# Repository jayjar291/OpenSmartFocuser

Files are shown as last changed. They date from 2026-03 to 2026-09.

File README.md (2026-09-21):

# OpenSmartFocuser

OpenSmartFocuser is an open-source telescope focuser project with:
- ESP32-S3 firmware (display/menu, motor control, serial command handling)
- an INDI driver scaffold for host-side integration
- hardware design files for PCB and related fabrication assets

## Build Targets

- `firmware/` contains the PlatformIO project for the device firmware.
- `drivers/indi/` contains the CMake-based INDI focuser driver.

## Folder Structure

```text
OpenSmartFocuser/
├── .github/
│   ├── ISSUE_TEMPLATE/        # GitHub issue templates
│   └── workflows/             # CI workflows (firmware and INDI driver builds)
├── docs/                      # Project documentation and operating notes
├── drivers/
│   └── indi/                  # INDI driver scaffold and CMake config
├── firmware/
│   ├── include/               # Firmware headers/config
│   ├── src/                   # Firmware source code
│   ├── platformio.ini         # PlatformIO project config
│   └── backup/                # Local backup files
└── hardware/
    ├── README.md              # Hardware folder overview
    ├── cad/                   # Mechanical CAD-related files
    │   └── README.md          # CAD file overview
    └── pcb/                   # KiCad project and fabrication outputs
        ├── README.md          # PCB project overview
        └── fabrication/       # Fabrication export guidance and outputs
```

## Continuous Integration

- `firmware-build.yml` builds the firmware project on Ubuntu with PlatformIO.
- `indi-driver-build.yml` configures and builds the INDI driver on Ubuntu with system INDI, Nova, GSL, and ZLIB development packages.

## Local Builds

Firmware:

```bash
cd firmware
pio run
```

INDI driver:

```bash
cd drivers/indi
cmake -S . -B build
cmake --build build --parallel
sudo cmake --install build
sudo udevadm control --reload-rules
sudo udevadm trigger
```

The INDI driver build expects CMake, a C++ compiler, and the development packages for INDI, Nova, GSL, and ZLIB.
The install step also deploys a udev rule that creates the stable serial symlink `/dev/OSF` for OpenSmartFocuser devices (USB VID:PID `1209:F0C1`).

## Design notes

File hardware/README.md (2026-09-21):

# Hardware

This folder contains the mechanical and electronic source files for the OpenSmartFocuser build.

## Folder Structure

```text
hardware/
├── cad/  # Mechanical CAD models and related design artifacts
└── pcb/  # KiCad project files and fabrication outputs
```
├── cad/   # Mechanical CAD models, drawings, and exports
└── pcb/   # KiCad PCB source files and fabrication assets
```

## What Belongs Here

- Mechanical source files used to model the focuser assembly.
- PCB design files used to route, review, and manufacture the controller board.
- Exported files that are still part of the design source, such as STEP, DXF, and fabrication references.

## Related Files

- See [CAD files](cad/README.md) for the mechanical design folder.
- See [PCB files](pcb/README.md) for the KiCad project and fabrication workflow.

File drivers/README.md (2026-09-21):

# Drivers

Host-side driver integrations for OpenSmartFocuser.

## Folder Structure

```text
drivers/
└── indi/  # INDI focuser driver source, build files, and XML metadata
```

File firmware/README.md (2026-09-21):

# Firmware

ESP32-S3 firmware for OpenSmartFocuser, including motor control, menu/display UX, and serial command handling.

## Folder Structure

```text
firmware/
├── include/        # Firmware headers and configuration values
├── src/            # Firmware implementation files
├── platformio.ini  # PlatformIO build configuration
└── backup/         # Local backup snapshots (not part of firmware runtime)
```

## Build

```bash
cd firmware
pio run
```

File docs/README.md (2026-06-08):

# Documentation

This folder contains the operating notes for the firmware, menu system, serial protocol, and hardware configuration.

## What the Focuser Can Do

- Move the focuser to an absolute step position.
- Move the focuser relative to the current position.
- Home the focuser and report position, speed, limits, and movement state.
- Store, recall, edit, and remove presets.
- Control optional add-ons such as a shutter servo and flat panel.
- Run the on-device menu for local operation and settings changes.

## Menu Navigation

The on-device menu is driven by the physical buttons defined in the board pin configuration.

- `UP` moves through menu items or increases a setting.
- `DOWN` moves through menu items or decreases a setting.
- `SELECT` opens the highlighted item, confirms a setting, or starts the selected action.
- `ENDSTOP` is used by the firmware as a hardware input for homing and safety logic, not as a normal menu button.
- `BOOT` is the ESP32 bootloader pin and is used for flashing or recovery.

The main menu currently exposes presets, device information, homing, settings, motor enable/disable, and optional add-on controls when those features are compiled in.

## Serial Protocol

Serial commands must be framed as `:TOKENpayload#`.

The protocol is intended for host software, automation, and debugging. Use the commands below when you need to query state, control motion, manage presets, or integrate with external software.

### Status and Query Commands

- `:PP#` heartbeat. Use this to confirm the device is alive and the serial link is working.
- `:GP#` get the current focuser position in steps. Use this before or after movement when syncing state with host software.
- `:GM#` get the current movement state. Use this to check whether the focuser is idle, moving, homing, or in error.
- `:GS#` get the current speed preset. Use this when a client needs to mirror the active speed setting.
- `:GL#` get the configured software limits. Use this before issuing travel commands if your client needs to enforce range checks.
- `:CI#` get the configured motor current in milliamps. Use this for diagnostics or driver verification.
- `:CU#` get the configured microstep setting. Use this for diagnostics or startup validation.
- `:VF#` get firmware version. This command is listed in the protocol index but is currently a placeholder in the firmware.

### Movement Commands

- `:MA<steps>#` move to an absolute position. Use this for direct positioning when the target step count is already known.
- `:MR<steps>#` move relative to the current position. Use this for jog-style movement or small corrections.
- `:MH#` halt motion immediately. Use this as the emergency stop command.
- `:MS<0-4>#` set the movement speed preset. Use this when you need to switch between the configured speed profiles.
- `:SP<steps>#` override the current position. Use this only when you need to re-synchronize the software position after maintenance or a manual mechanical reset.

### Homing and System Commands

- `:HM#` start homing. Use this to find the reference position after power-up or when you need to re-establish the travel origin.
- `:TM#` toggle the motor enable state. Use this for quick local control when the current state is unknown.
- `:DM#` disable the motor. Use this when you want to cut motor drive without changing the rest of the device state.
- `:EM#` enable the motor. Use this before moving if the motor has been disabled.
- `:RB#` reboot the system. Use this only when the device is idle or when you intentionally need a restart.

### Preset Commands

- `:PL#` list stored presets. Use this to populate a preset browser in host software.
- `:PR<presetId>#` get a preset by ID. Use this when you need the name and step value for one stored preset.
- `:PA<steps>,<name>#` add a new preset. Use this when saving the current position as a named target.
- `:PS<presetId>,<steps>,<name>#` update an existing preset. Use this when renaming or retargeting a stored preset.
- `:PG<presetId>#` go to a preset by ID. Use this for one-touch recall from the stored list.
- `:PC<presetId>#` delete a preset by ID. Use this when removing outdated entries.

### Star Map Target Commands

- `:TI#` get the current DSO target.
- `:TG<RA>,<DEC>,<name>#` set the DSO target.
- `:TC#` clear the DSO target.

These commands are currently placeholders in the firmware and return a temporary response. Do not depend on them for production automation yet.

### Optional Add-on Commands

- `:AQ#` query installed add-ons. Use this to detect whether the shutter or flat panel is present.
- `:FP<brightness>#` set flat panel brightness from 0 to 255. Use this only when the flat panel add-on is installed.
- `:SV<position>#` set the shutter position. Use this only when the shutter add-on is installed.

## Optional Add-ons

The firmware can expose two optional accessories.

- Shutter servo: controlled by `PIN_SHUTTER_SERVO` and exposed through the shutter menu and `:SV` command.
- Flat panel: controlled by `PIN_FLAT_FRAME_PANEL` and exposed through the menu and `:FP` command.

If an add-on is not compiled into the current build, the related menu items and commands should not be relied on.

## Current Pin Definitions

These pins come from [firmware/include/board_config/esp32_s3_devkitc1_pins.h](../firmware/include/board_config/esp32_s3_devkitc1_pins.h).

| Function | Pin | Notes |
| --- | ---: | --- |
| `PIN_TMC_STEP` | 4 | Step output for the TMC2209 driver |
| `PIN_TMC_DIR` | 5 | Direction output for the TMC2209 driver |
| `PIN_TMC_ENABLE` | 6 | Enable output for the TMC2209 driver |
| `PIN_TMC_UART_TX` | 15 | UART TX for driver configuration |
| `PIN_TMC_UART_RX` | 16 | UART RX for driver configuration |
| `PIN_LCD_SCK` | 12 | ST7789 SPI clock |
| `PIN_LCD_MOSI` | 11 | ST7789 SPI data out |
| `PIN_LCD_MISO` | -1 | Not used |
| `PIN_LCD_CS` | 10 | ST7789 chip select |
| `PIN_LCD_DC` | 9 | ST7789 data/command |
| `PIN_LCD_RST` | 8 | ST7789 reset |
| `PIN_LCD_BL` | 17 | Backlight control |
| `PIN_LED` | 48 | On-board/status LED |
| `PIN_BUTTON_UP` | 35 | Menu up input |
| `PIN_BUTTON_DOWN` | 37 | Menu down input |
| `PIN_BUTTON_SELECT` | 36 | Menu select input |
| `PIN_BUTTON_ENDSTOP` | 38 | Endstop/safety input |
| `PIN_BUTTON_BOOT` | 0 | Bootloader input |
| `PIN_SHUTTER_SERVO` | 18 | Optional shutter add-on |
| `PIN_FLAT_FRAME_PANEL` | 13 | Optional flat panel add-on |

## Notes

- The menu and serial protocol should stay aligned with the current firmware behavior.
- If you change the board or add-ons, update the pin definition file first and then refresh this document.
- If a serial command is added or removed, update the command list here at the same time.

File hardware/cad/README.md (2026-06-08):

# CAD

This folder stores the mechanical design files for the OpenSmartFocuser assembly.

## Folder Structure

```text
cad/
├── 3mf/   # Printable model exports
├── step/  # Assembly and fit-check models
└── pcb mount.dxf  # 2D reference drawing for the PCB mount
```

## File Types

- `3mf/` contains printable parts for enclosure and accessory checks.
- `step/` contains solid models for CAD import, fit checks, and assembly review.
- `pcb mount.dxf` is the 2D drawing used for mount or cut reference work.

## Use Case

Use this folder when you need to:

- review the physical assembly before printing or machining.
- verify clearances between the drawtube, housing, and mounted electronics.
- export or update models for enclosure and mechanical integration.

When mechanical dimensions change, update the source CAD files first and then regenerate the derived exports.

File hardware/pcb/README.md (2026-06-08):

# PCB

This folder contains the KiCad project and related fabrication assets for the OpenSmartFocuser controller board.

## Folder Structure

```text
pcb/
├── OpenSmartFocuser/  # KiCad project source files
├── fabrication/       # Fabrication export guidance and output files
```

## Contents

- `OpenSmartFocuser/` contains the schematic, board layout, symbols, footprints, and project metadata.
- `fabrication/` is reserved for Gerber, drill, BOM, and pick-and-place outputs.

## Use Case

Use this folder when you need to:

- edit the schematic or PCB layout in KiCad.
- review net names, footprints, and placement.
- generate manufacturer-ready fabrication files.

Keep fabrication exports separate from the source project so the design files remain easy to review and version.

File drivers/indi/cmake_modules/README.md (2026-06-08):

This folder is intentionally scaffolded for INDI CMake modules.

Copy the following files from the upstream libindi repository when you are ready to build:
- CMakeCommon.cmake
- FindINDI.cmake
- FindNova.cmake
- UnityBuild.cmake

Source:
https://github.com/indilib/indi/tree/master/cmake_modules

The GitHub Actions INDI driver workflow fetches these files automatically during CI builds.

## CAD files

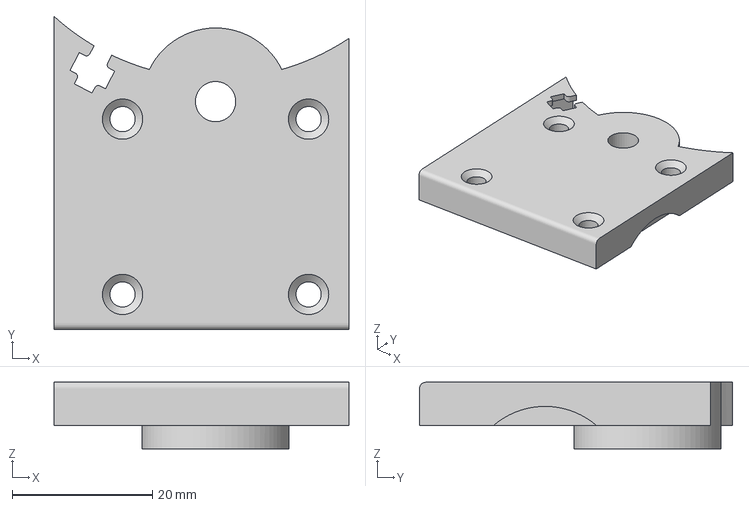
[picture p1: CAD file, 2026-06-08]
hardware/cad/3mf/Cap.3mf
42.0 x 44.6 x 9.50 mm

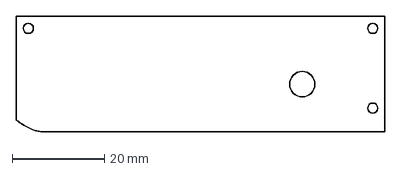
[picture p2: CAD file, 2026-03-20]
hardware/cad/pcb mount.dxf
80.0 x 25.0 mm

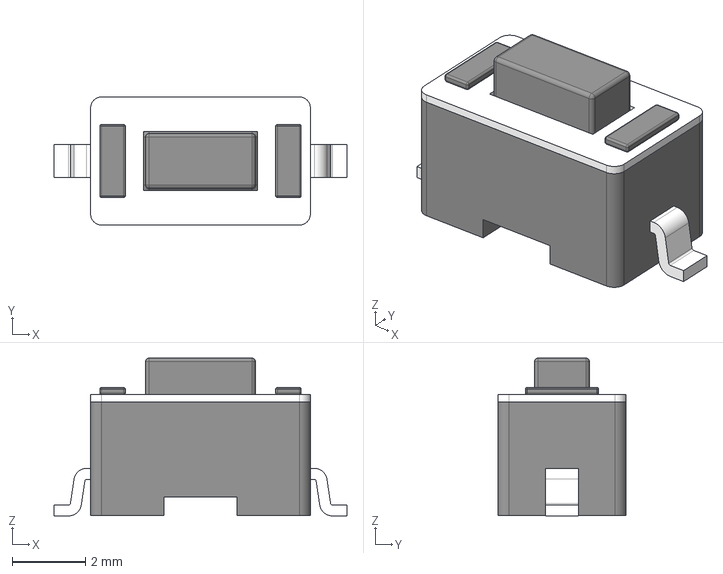
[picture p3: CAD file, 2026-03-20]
hardware/pcb/OpenSmartFocuser/EASYEDA_MODELS/SW-SMD_L6.0-W3.5-LS8.0-1.step
8.00 x 3.50 x 4.31 mm

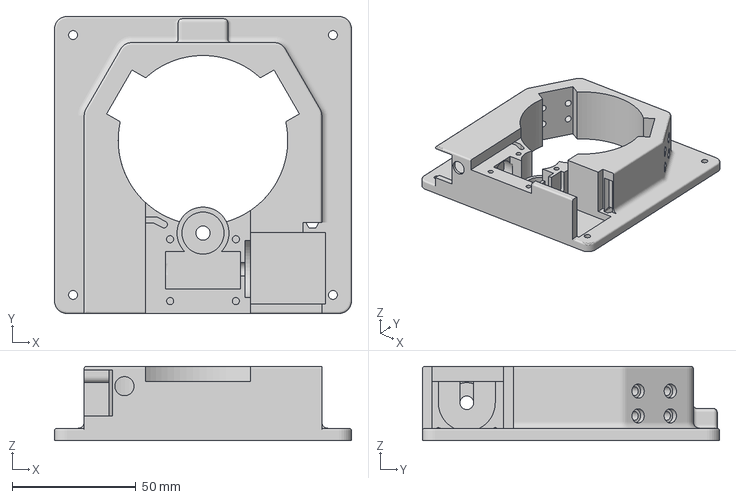
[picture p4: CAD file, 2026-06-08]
hardware/cad/3mf/Housing.3mf
120.0 x 120.0 x 30.0 mm

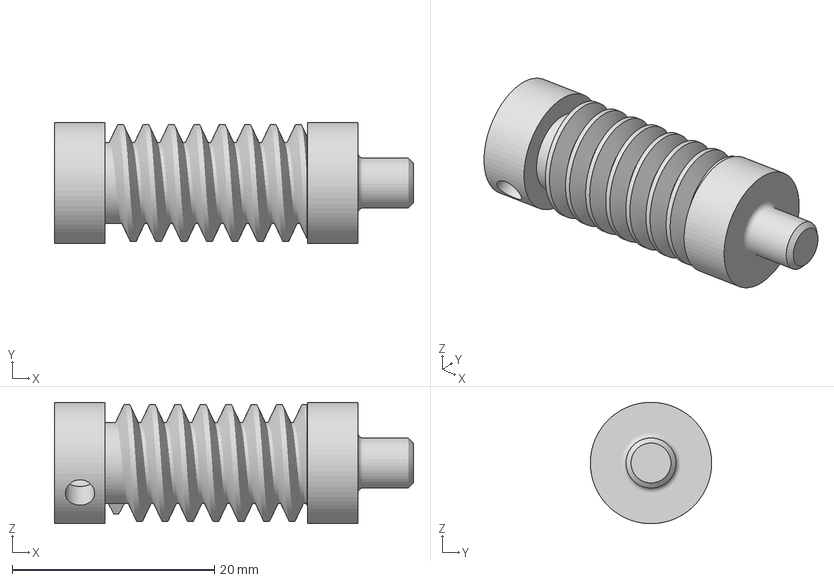
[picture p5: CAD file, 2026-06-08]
hardware/cad/3mf/Input.3mf
35.5 x 12.0 x 12.0 mm

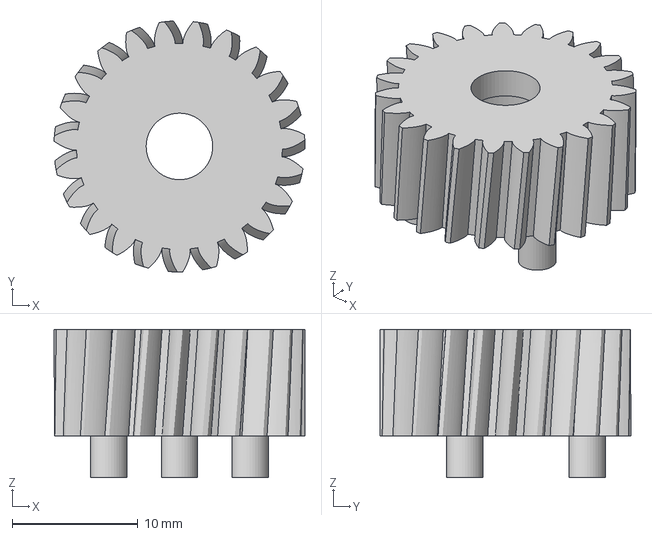
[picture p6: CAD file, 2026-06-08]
hardware/cad/3mf/Output.3mf
20.0 x 20.0 x 11.8 mm

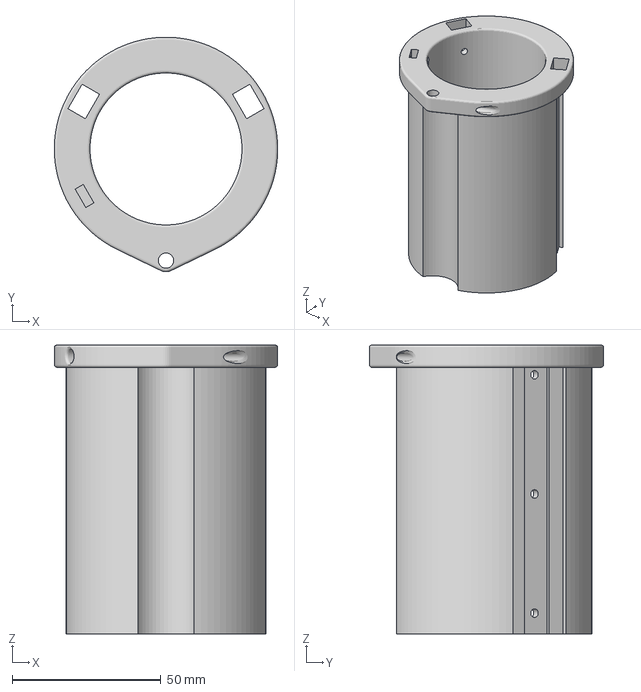
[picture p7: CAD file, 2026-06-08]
hardware/cad/3mf/Drawtube.3mf
75.0 x 78.7 x 97.0 mm

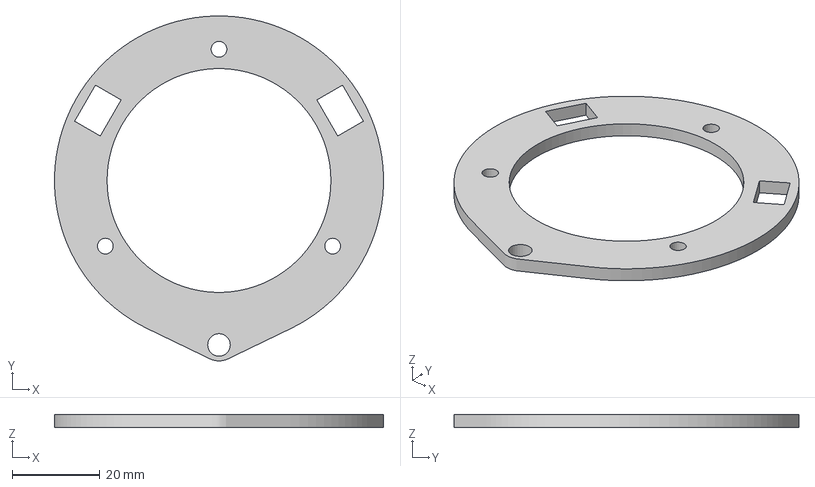
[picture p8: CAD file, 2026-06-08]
hardware/cad/3mf/End Cap.3mf
75.0 x 78.6 x 3.00 mm

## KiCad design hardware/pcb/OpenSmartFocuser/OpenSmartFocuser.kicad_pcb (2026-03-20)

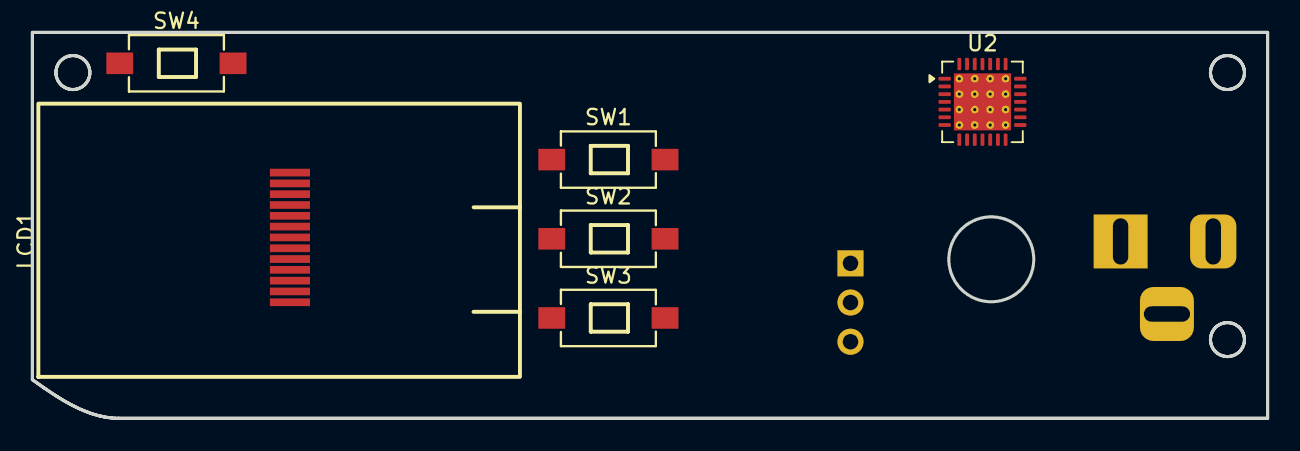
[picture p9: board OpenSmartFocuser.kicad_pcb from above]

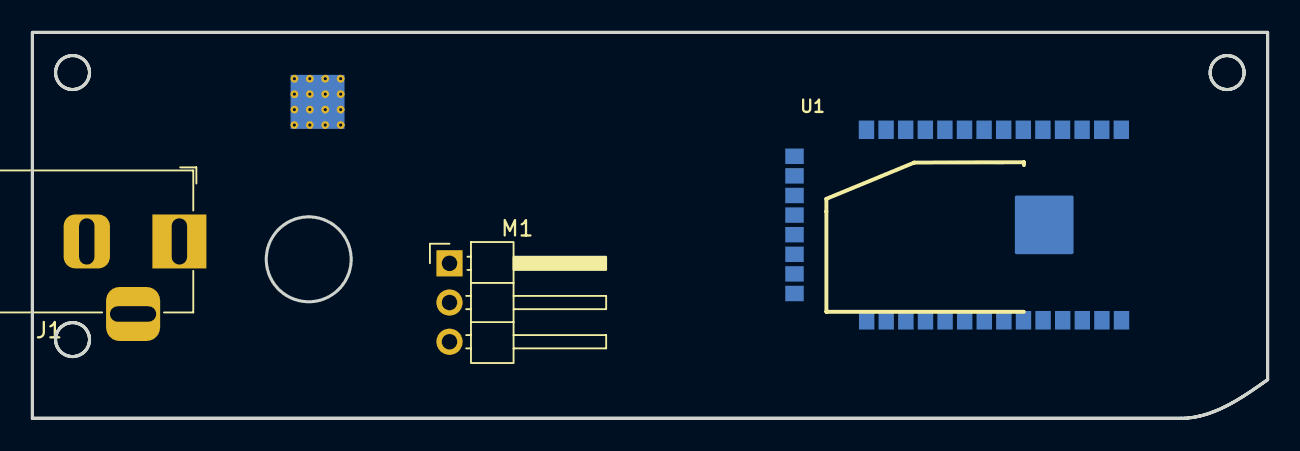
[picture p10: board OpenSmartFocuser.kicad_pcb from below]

Board: 2 copper layers, 80.0 x 25.0 mm, 9 parts (3 on the bottom side), 2 nets, no tracks yet.

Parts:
J1: Barrel_Jack_Switch; BarrelJack_Horizontal
LCD1: LCD-SMD_1.14IPS-LCD
M1: Motor_Servo; PinHeader_1x03_P2.54mm_Horizontal
SW1, SW2, SW3, SW4: SW-SMD_L6.0-W3.5-LS8.0-1
U1: NanoS3
U2: TMC2209-LA; VQFN-28-1EP_5x5mm_P0.5mm_EP3.7x3.7mm_ThermalVias

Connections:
unnamed: U2.3 (GND), U2.18 (GND), U2.29 (GND)
unnamed: U2.22 (VS), U2.28 (VS)

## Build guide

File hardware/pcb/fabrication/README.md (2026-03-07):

# Fabrication Outputs

Place Gerber files, BOM, and pick-and-place exports here after generating from KiCad.

## Files Expected
- `gerbers/` — Gerber + drill files (ZIP for fab upload)
- `BOM.csv` — Bill of Materials
- `positions.csv` — Pick and place / CPL file

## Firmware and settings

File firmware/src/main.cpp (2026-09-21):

#include <Arduino.h>
#include <FastAccelStepper.h>
#include <TMCStepper.h>
#include <freertos/FreeRTOS.h>
#include <freertos/task.h>
#if CONFIG_TINYUSB_ENABLED
#include <USB.h>
#endif
#include "addons.h"
#include "config.h"
#include "debug_serial.h"
#include "menu.h"
#include "movement.h"
#include "serial_command_handler.h"
#include "preset.h"

/*
 * Hardware interface constants for TMC2209 UART control.
 */
static constexpr float TMC_R_SENSE = 0.11f;
static constexpr uint8_t TMC_STEPPER_UART_INDEX = 1;
// globlal variables for idle star map center coordinates
float idleMapCenterRaDeg = IDLE_STAR_MAP_CENTER_RA_DEG;
float idleMapCenterDecDeg = IDLE_STAR_MAP_CENTER_DEC_DEG;

/*
 * Global hardware driver instances used during initialization and runtime.
 */
HardwareSerial tmcSerial(TMC_STEPPER_UART_INDEX);
FastAccelStepperEngine stepperEngine;
FastAccelStepper* focuserStepper = nullptr;
TMC2209Stepper focuserDriver(&tmcSerial, TMC_R_SENSE, TMC_DRIVER_ADDRESS);

/*
 * Global motor enable state controlled from the main menu.
 */
bool motorEnabled = false;

static TaskHandle_t motorTaskHandle = nullptr;

#if CONFIG_TINYUSB_ENABLED
namespace {

struct UsbDescriptorConfigurator {
  UsbDescriptorConfigurator() {
    USB.VID(0x1209);
    USB.PID(0xF0C1);
    USB.manufacturerName("JayTek");
    USB.productName("OpenSmartFocuser");
  }
};

UsbDescriptorConfigurator gUsbDescriptorConfigurator;

}  // namespace
#endif

static void motorTask(void* /*param*/) {
  static constexpr uint32_t kHealthCheckIntervalMs = 250;
  uint32_t lastHealthCheckMs = 0;

  for (;;) {
    Movement::processEndstopEvent();
    Movement::updateSoftEndstops();
    Movement::updateHoming();
    Movement::updatePositionPersistence();
    Movement::updateMotorIdleTimeout();
    
    const uint32_t now = millis();
    if (now - lastHealthCheckMs >= kHealthCheckIntervalMs) {
      Movement::healthCheck();
      lastHealthCheckMs = now;
    }
    
    vTaskDelay(pdMS_TO_TICKS(1));
  }
}

/*
 * One-time startup sequence for serial logging, UI initialization,
 * and TMC driver bring-up.
 */
void setup() {
#if CONFIG_TINYUSB_ENABLED && !ARDUINO_USB_CDC_ON_BOOT
  // Initialize TinyUSB descriptors before CDC starts so host sees custom IDs/names.
  USB.VID(0x1209);
  USB.PID(0xF0C1);
  USB.manufacturerName("JayTek");
  USB.productName("OpenSmartFocuser");
  USB.begin();
#endif

  Serial.begin(115200);
  delay(100);

#if CONFIG_TINYUSB_ENABLED
  const uint32_t serialWaitStartMs = millis();
  while (!Serial && (millis() - serialWaitStartMs) < 2000) {
    delay(10);
  }
#endif

  SerialCommandHandler::begin(Serial);

  DebugSerial::printFramed("Setup: begin");
  DebugSerial::printFramedValue("Free heap at startup (bytes) ", ESP.getFreeHeap(), " ");
  
  initMenu();

  ledcSetup(7, 5000, 8); // Set up PWM on channel 7 with 5 kHz frequency and 8-bit resolution for LCD backlight control
  ledcAttachPin(PIN_LCD_BL, 7); // Attach the LCD backlight pin to PWM channel 7
  
  DebugSerial::printFramed("Setup: initialize addons");
  DebugSerial::printFramedValue("Free heap (bytes) ", ESP.getFreeHeap(), " ");
  if (Addons::isEnabled()) {
    Addons::initializeAddons();
  }

  DebugSerial::printFramed("Setup: initializeDriver");
  Movement::initializeDriver();
  DebugSerial::printFramedValue("Free heap (bytes) ", ESP.getFreeHeap(), " ");
  
  DebugSerial::printFramed("Setup: preset begin");
  preset::begin();
  DebugSerial::printFramedValue("Free heap (bytes) ", ESP.getFreeHeap(), " ");

  // Core 0 handles motor/homing/endstop tasks. loop() remains on Core 1 for UI/menu.
  DebugSerial::printFramed("Setup: create motor task");

  BaseType_t taskCreated = xTaskCreatePinnedToCore(
    motorTask,
    "motorTask",
    4096,
    nullptr,
    2,
    &motorTaskHandle,
    0);
    if (taskCreated != pdPASS) {
      DebugSerial::printFramed("Failed to start motor task on Core 0");
      return;
    }
  DebugSerial::printFramedValue("Free heap (bytes) ", ESP.getFreeHeap(), " ");



  DebugSerial::printFramed("Setup: done");
}

/*
 * Main runtime loop: services menu input/rendering and applies
 * current brightness setting to the display backlight PWM pin.
 */
void loop() {
  menu.loop();
  SerialCommandHandler::poll();
  Movement::setSpeedSetting(getFocusSpeedSetting());
  //analogWrite(PIN_LCD_BL, getBrightnessSetting() * 255 / 100);
  ledcWrite(7, getBrightnessSetting() * 255 / 100); // Apply brightness setting to LCD backlight PWM channel
  Addons::detachServos(); // Detach servos if they have been idle for a while to reduce power consumption and prevent jitter
}

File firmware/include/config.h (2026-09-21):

#pragma once

//#include "board_config/esp32_s3_devkitc1_pins.h"
#include "board_config/esp32_s3_mainboard_OSF.h"

/*
 * TFT_eSPI is configured through a custom setup header passed in build flags.
 */
#define TFT_ESPI_SETUP_HEADER "TFT_eSPI_Setup.h"

/*
 * Generic motion and UART timing configuration for the focuser driver stack.
 * System now runs in full-step mode (1 microstep) for all operations.
 */
#define TMC_UART_BAUDRATE 115200
#define TMC_DRIVER_ADDRESS 0b00
#define TMC_MAX_SPEED 30000
#define TMC_MAX_ACCELERATION 50000
// Speed settings for different focus jog modes and preset saving.
#define FINE_FOCUS_SPEED_STEPS_PER_SEC 3000
#define SLOW_FOCUS_SPEED_STEPS_PER_SEC 6000
#define MEDIUM_FOCUS_SPEED_STEPS_PER_SEC 9000
#define FAST_FOCUS_SPEED_STEPS_PER_SEC 12000
#define MAX_FOCUS_SPEED_STEPS_PER_SEC 15000
#define HOMING_SPEED_STEPS_PER_SEC 20000

/*
 * Enables framed debug text output on Serial as !{message}*.
 * Protocol responses remain unchanged.
 */
#define SERIAL_DEBUG_ENABLED true

/*
 * TMC2209 electrical and mode settings used during driver initialization.
 */
#define TMC_RMS_CURRENT 650
#define MOTOR_IDLE_TIMEOUT_MS 30000
#define TMC_MICROSTEPS 16
#define TMC_SPREAD_CYCLE true

/*
 * Focuser travel calibration.
 * Measured: 184000 full steps (HOMING_MICROSTEPS=1) = 4.74 mm.
 * FOCUSER_STEPS_PER_MM is in runtime step units (full-step mode).
 */
#define FOCUSER_STEPS_PER_MM 38819

/*
 * Software travel limits (enforced in normal operating mode).
 */
#define FOCUSER_SOFT_MIN_MM    0
#define FOCUSER_SOFT_MAX_MM    55
#define FOCUSER_SOFT_MIN_STEPS 0
#define FOCUSER_SOFT_MAX_STEPS (FOCUSER_SOFT_MAX_MM * FOCUSER_STEPS_PER_MM)
#define FOCUSER_HOMING_RETURN_MM 1

/*
 * User-facing device defaults used by the menu/UI layer.
 */
#define DEFAULT_BRIGHTNESS 75

/*
 * Enables PSRAM initialization during startup when hardware supports it.
 * Set to true to attempt PSRAM init, false to skip.
 */
#define ENABLE_PSRAM true

/*
 * Hard-coded preset names exposed in the menu when adding a new preset.
 * Keep this list at or below preset::kMaxPresets entries.
 */
#define PRESET_NAME_OPTIONS { \
	"Fine Focus",              \
	"Clear",              \
	"Dark",              \
	"Red",              \
	"Green",              \
	"Blue",              \
	"Luminance",              \
	"Ha",              \
	"O-III",              \
	"S-II",             \
	"UV",             \
	"IR"              \
}

/*
 * Idle star-map center (J2000-like sky coordinates, degrees).
 * Right ascension wraps 0..360; declination is clamped to -90..90.
 */
#define IDLE_STAR_MAP_CENTER_RA_DEG 90.0f
#define IDLE_STAR_MAP_CENTER_DEC_DEG 20.0f

/*
 * Select which star catalog is compiled into the idle sky map.
 * Options in this repo: "stars.h", "stars_large.h", "stars_6.5.h"
 */
#define IDLE_STAR_CATALOG_HEADER "stars_6.5.h"

/*
 * Astrophotography UI theme (RGB565): red-dominant to preserve dark adaptation.
 * Tune these values to restyle the full menu system from one place.
 */
#define MENU_COLOR_BG 0x0000
#define MENU_COLOR_TEXT 0xF800
#define MENU_COLOR_SELECTION_BORDER 0xF800
#define MENU_COLOR_SELECTION_FILL 0x4800
#define MENU_COLOR_SCROLLBAR 0xC800

/*
 * Idle screen component colors (RGB565).
 */
#define IDLE_COLOR_BG MENU_COLOR_BG
#define IDLE_COLOR_TEXT MENU_COLOR_TEXT
#define IDLE_COLOR_BOTTOM_BAR 0x2000
#define IDLE_COLOR_RIGHT_BAR 0x2800
#define IDLE_COLOR_RIGHT_BAR_BORDER MENU_COLOR_SELECTION_BORDER
#define IDLE_COLOR_SPACER 0x7800

#define HAS_SHUTTER true
#define HAS_FLAT_FRAME_PANEL true

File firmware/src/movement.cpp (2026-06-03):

#include <Arduino.h>
#include <FastAccelStepper.h>
#include <Preferences.h>
#include <TMCStepper.h>
#include "config.h"
#include "debug_serial.h"
#include "movement.h"

extern FastAccelStepper* focuserStepper;
extern TMC2209Stepper focuserDriver;
extern bool motorEnabled;
extern HardwareSerial tmcSerial;
extern FastAccelStepperEngine stepperEngine;

uint32_t speedHz = SLOW_FOCUS_SPEED_STEPS_PER_SEC;

namespace {

constexpr const char* kCurrentPositionNamespace = "CurrentPos";
constexpr const char* kCurrentPositionKey = "steps";

volatile bool homingInProgress = false;
volatile bool homingReturnInProgress = false;
volatile bool endstopInterruptPending = false;
volatile bool endstopTriggeredDuringHoming = false;
bool jogActive = false;
uint32_t lastMotorActivityMs = 0;
bool uartConnectionLost = false;
uint32_t lastUartReconnectAttemptMs = 0;
bool uartConnectedCached = false;
uint16_t driverCurrentCachedMa = 0;
uint16_t driverMicrostepsCached = 0;

constexpr uint32_t kUartReconnectAttemptIntervalMs = 500;

bool wasMoving = false;

void touchMotorActivity() {
  lastMotorActivityMs = millis();
}

void configureTmcDriverRegisters() {
  focuserDriver.begin();
  focuserDriver.toff(4);
  focuserDriver.rms_current(TMC_RMS_CURRENT);
  focuserDriver.en_spreadCycle(TMC_SPREAD_CYCLE);
  focuserDriver.microsteps(TMC_MICROSTEPS);
  focuserDriver.pwm_autoscale(true);
}

bool isEndstopTriggered() {
  return digitalRead(PIN_BUTTON_ENDSTOP) == LOW;
}

void IRAM_ATTR onEndstopInterrupt() {
  endstopInterruptPending = true;
  if (homingInProgress || homingReturnInProgress) {
    endstopTriggeredDuringHoming = true;
  }
}

} // namespace

namespace Movement {


void setMotorEnabledState(bool enabled) {
  if (focuserStepper == nullptr) {
    motorEnabled = enabled;
    return;
  }

  motorEnabled = enabled;
  touchMotorActivity();

  if (enabled) {
    focuserStepper->enableOutputs();
    return;
  }

  jogActive = false;
  focuserStepper->stopMove();
  focuserStepper->disableOutputs();
}


void initializeDriver() {
  pinMode(PIN_TMC_STEP, OUTPUT);
  digitalWrite(PIN_TMC_STEP, LOW);
  pinMode(PIN_TMC_DIR, OUTPUT);
  digitalWrite(PIN_TMC_DIR, LOW);
  pinMode(PIN_TMC_ENABLE, OUTPUT);
  digitalWrite(PIN_TMC_ENABLE, HIGH);
  pinMode(PIN_BUTTON_ENDSTOP, INPUT_PULLUP);
  attachInterrupt(digitalPinToInterrupt(PIN_BUTTON_ENDSTOP), onEndstopInterrupt, FALLING);

  tmcSerial.begin(TMC_UART_BAUDRATE, SERIAL_8N1, PIN_TMC_UART_RX, PIN_TMC_UART_TX);

  configureTmcDriverRegisters();

  stepperEngine.init();
  
  focuserStepper = stepperEngine.stepperConnectToPin(PIN_TMC_STEP, DRIVER_RMT);
  DebugSerial::printFramedValue("focuserStepper ptr: ", (uint32_t)focuserStepper, "");
  if (focuserStepper == nullptr) {
    DebugSerial::printFramed("stepperConnectToPin failed");
    return;
  }
  focuserStepper->setDirectionPin(PIN_TMC_DIR);
  focuserStepper->setEnablePin(PIN_TMC_ENABLE, true); // active LOW: LOW = motor enabled
  focuserStepper->setSpeedInHz(TMC_MAX_SPEED);
  focuserStepper->setAcceleration(TMC_MAX_ACCELERATION);
  setMotorEnabledState(false);
  
  uartConnectedCached = (focuserDriver.test_connection() == 0);
  if (uartConnectedCached) {
    driverCurrentCachedMa = focuserDriver.rms_current();
    driverMicrostepsCached = focuserDriver.microsteps();
  } else {
    driverCurrentCachedMa = 0;
    driverMicrostepsCached = 0;
  }
  uartConnectionLost = false;
  
  lastUartReconnectAttemptMs = millis();
  
  loadPersistentCurrentPosition();
  
}

void healthCheck() {
  if (focuserStepper == nullptr) {
    return;
  }

  const bool uartConnected = (focuserDriver.test_connection() == 0);
  if (uartConnected) {
    if (uartConnectionLost) {
      DebugSerial::printFramed("TMC UART connection restored. Reinitializing registers.");
      configureTmcDriverRegisters();
      uartConnectionLost = false;
      lastUartReconnectAttemptMs = millis();
      DebugSerial::printFramed("TMC driver registers reloaded after reconnect.");
    }
    uartConnectedCached = true;
    driverCurrentCachedMa = focuserDriver.rms_current();
    driverMicrostepsCached = focuserDriver.microsteps();
    return;
  }

  uartConnectedCached = false;
  driverCurrentCachedMa = 0;
  driverMicrostepsCached = 0;

  if (!uartConnectionLost) {
    uartConnectionLost = true;
    DebugSerial::printFramed("TMC UART connection lost. Entering reconnect mode.");
    setMotorEnabledState(false);
    DebugSerial::printFramed("Motor disabled while UART is disconnected.");
  }

  const uint32_t now = millis();
  if (now - lastUartReconnectAttemptMs < kUartReconnectAttemptIntervalMs) {
    return;
  }

  lastUartReconnectAttemptMs = now;
  tmcSerial.end();
  tmcSerial.begin(TMC_UART_BAUDRATE, SERIAL_8N1, PIN_TMC_UART_RX, PIN_TMC_UART_TX);
  DebugSerial::printFramed("Attempting TMC UART reconnect...");
}

void toggleMotorEnabled() {
  setMotorEnabledState(!motorEnabled);
}

bool isMotorEnabled() {
  return motorEnabled;
}

void jogForward() {
  if (focuserStepper == nullptr || homingInProgress || homingReturnInProgress) {
    return;
  }
  if (!motorEnabled) {
    setMotorEnabledState(true);
  }
  // When jogging forward, we want to prevent moving further if we are already at or beyond the soft endstop limit.
  if (!checkSoftEndstops(focuserStepper->getCurrentPosition() + 250)) {
    DebugSerial::printFramedValue("target position is" , focuserStepper->getCurrentPosition() + 250,"target position is outside of soft endstop limits. Jog movement ignored.");
    return;
  }
  touchMotorActivity();
  setMotorEnabledState(true);
  jogActive = true;
  focuserStepper->runForward();
}

void jogBackward() {
  if (focuserStepper == nullptr || homingInProgress || homingReturnInProgress) {
    return;
  }
  if (!motorEnabled) {
    setMotorEnabledState(true);
  }
  if (isEndstopTriggered())
  {
    DebugSerial::printFramed("Endstop is triggered. Jog backward ignored.");
    return;
  }
  touchMotorActivity();
  setMotorEnabledState(true);
  jogActive = true;
  focuserStepper->runBackward();
}

void stopJog() {
  if (focuserStepper == nullptr || homingInProgress || homingReturnInProgress) {
    return;
  }
  if (jogActive) {
    focuserStepper->stopMove();
    jogActive = false;
    touchMotorActivity();
  }
}

void halt() {
  if (focuserStepper == nullptr) {
    return;
  }
  focuserStepper->forceStop();
  jogActive = false;
  homingReturnInProgress = false;
  homingInProgress = false;
  setMotorEnabledState(false);

  noInterrupts();
  endstopInterruptPending = false;
  endstopTriggeredDuringHoming = false;
  interrupts();

  touchMotorActivity();
}
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

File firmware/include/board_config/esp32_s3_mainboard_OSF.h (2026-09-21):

#pragma once

/*
 * TMC2209 stepper driver control and single-wire UART pins.
 */
#define PIN_TMC_STEP                5
#define PIN_TMC_DIR                 6
#define PIN_TMC_ENABLE              7
#define PIN_TMC_UART_TX             8
#define PIN_TMC_UART_RX             9

/*
 * ST7789 display SPI and control pins.
 */
#define PIN_LCD_CS                  10
#define PIN_LCD_MOSI                11   
#define PIN_LCD_SCK                 12
#define PIN_LCD_DC                  13
#define PIN_LCD_RST                 14
#define PIN_LCD_BL                  15
#define PIN_LCD_MISO                -1

/*
 * On-board/status LED output.
 */
#define PIN_LED                     48

/*
 * Physical button inputs used by menu navigation and control.
 */
#define PIN_BUTTON_UP               16
#define PIN_BUTTON_DOWN             18
#define PIN_BUTTON_SELECT           17
#define PIN_BUTTON_ENDSTOP          21
#define PIN_BUTTON_BOOT              0


//addon pins definitions

/*
* Shutter servo control pin.
*/
#define PIN_SHUTTER_SERVO           1

/*
* Flat frame panel control pin.
*/
#define PIN_FLAT_FRAME_PANEL        2

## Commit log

2026-03-07 added the kicad files
    [OpenSmartFocuser.kicad_pcb, OpenSmartFocuser.kicad_sch]
2026-03-20 removed AI readme files
    [SW-SMD_L6.0-W3.5-LS8.0-1.step, pcb mount.dxf]
2026-03-25 Refactor pin configuration and driver setup for TMC2209 and ST7789; add TFT_eSPI setup header
2026-03-25 Add custom screens for OpenMenuOS UI; implement idle and preset screens with button handling
2026-03-26 Update motion configuration and remove LX200 serial support
    - Increased TMC maximum speed to 80000 and acceleration to 15000.
    - Added homing speed configuration.
    - Removed LX200 serial handling files and references.
2026-03-27 Update motor speed configurations and enhance homing functionality
2026-03-27 Refactor motor control to use FastAccelStepper; update speed and acceleration settings
2026-04-06 Refactor code structure for improved readability and maintainability
    [OpenSmartFocuser.kicad_pcb]
2026-04-07 Fix debug output to use println for framing messages
2026-04-08 Refactor movement and serial command handling
    - Updated the `startHoming` function to streamline the homing process by removing redundant variable assignments and ensuring proper state management.
    - Enhanced the `updateHoming` function to include a response indicating the completion of the homing sequence.
    - Modified the serial command handler to improve command parsing and dispatching, including the addition of new commands for setting targets and handling presets.
    - Introduced a new menu system with structured screens and settings, allowing for better user interaction and configuration.
    - Added string constants for menu titles and options to improve code readability and maintainability.
    -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
2026-04-16 Enhance preset management and device info screens with new functionalities and UI updates
2026-05-12 Add motor idle timeout and health check functionality; implement serial commands for current and microsteps
2026-05-12 Add initial INDI driver scaffold with CMake configuration and necessary files
2026-05-12 Add OpenSmartFocuser Dummy Driver Implementation
    - Implemented the OpenSmartFocuserDummy class in indi_opensmartfocuser_focuser.cpp and its corresponding header file.
    - Added methods for connecting, disconnecting, moving the focuser, and managing properties in a simulated environment.
    - Updated XML configuration to reflect the new dummy driver name.
    - Enhanced .gitignore files to exclude build artifacts and IDE-specific files.
    - Introduced CMake modules for finding INDI and NOVA libraries, along with Unity build support.
2026-05-12 feat: add new serial command handlers for movement, homing, speed, and firmware version
2026-05-13 enhance movement control with endstop handling and speed settings
2026-05-13 remove debug print statement in jogForward function
2026-05-13 add motor control command handlers and integrate with movement functions
2026-05-13 add endstop handling functions and remove duplicate definitions
2026-05-13 refactor OpenSmartFocuser class and update XML configuration for driver
2026-05-15 add detailed comments for driver functionality and property management
2026-06-01 add toggle functionality for flat panel and shutter, update pin assignments, and enhance menu options
2026-06-02 update flat frame panel configuration, switch from Adafruit NeoPixel to FastLED, and enhance PWM setup for LCD backlight control
    TODO REMOVE FLAT FRAME
2026-06-03 refactor addon management: remove unused begin function, update flat panel pin configuration, and streamline brightness control
2026-06-06 chore: resolve merge conflicts with main
    [addons.cpp]
2026-06-08 Initial revision focuser 3D print files and CAD
    [Cap.3mf, Drawtube.3mf, End Cap.3mf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]
2026-06-08 Enhance documentation and CI workflows: - Update bug report template to specify component types. - Add build targets and CI details to README. - Create INDI driver build workflow for automated CI. - 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
2026-06-09 update CI workflow to use Ubuntu 24.04, enhance dependency installation, and switch to Debug build type
2026-06-09 Refactor USB handling: update serial interface to Stream, add USB descriptor configurator, and set VID/PID for TinyUSB
2026-06-09 Add udev rules for OpenSmartFocuser USB devices and update shutter angle limits
2026-06-28 Add board configuration for ESP32 S3 mainboard including pin definitions for TMC2209, ST7789 display, LED, buttons, and servos
2026-07-12 Add clampDecToViewport function to constrain declination within viewport limits
2026-07-12 Enhance OpenSmartFocuser: add target device discovery and refresh functionality
2026-09-07 Update .gitignore to include additional hardware files and modify config.h to comment out unused board configuration
